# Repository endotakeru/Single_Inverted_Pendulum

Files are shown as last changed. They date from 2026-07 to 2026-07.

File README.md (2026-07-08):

# Single Inverted Pendulum — Simulation + Hardware Control

An educational control-systems project: a cart on a rail balances a rod with a
mass on the end (an inverted pendulum) using PD feedback. It spans the full
stack — a **Python simulation** to design and understand the controller, an
**Arduino controller** for the real hardware rig, the **CAD/3D-printed**
mechanical design, and the **KiCad schematic** for the electronics.

## What the system is

```
            o   <- end bob (mass m1)
            |
            |   <- rod (mass m2, length l), angle theta from vertical
         [ cart ]  <- slides on a rail
   =========================  <- rail
            |
        cart force / motion   --->
```

* **State vector (used throughout):** `X = [x, x_dot, theta, theta_dot]`
  * `x` cart position [m], `x_dot` cart velocity [m/s]
  * `theta` pendulum angle from vertical [rad] (0 = upright), `theta_dot` [rad/s]
* **The actuator moves the CART, not the pendulum.** The pendulum is never pushed
  directly — it only reacts to the cart sliding underneath it. Balancing means
  moving the cart so it stays under the falling pendulum.

## Project structure

```
Single_Inverted_Pendulum/
├── Python_Simulation/             # the Python simulation (design + study)
│   ├── main.py                    #   runs the whole simulation start to finish
│   ├── params.py                  #   constants, simulation settings, PD gains
│   ├── dynamics.py                #   nonlinear equations of motion (the plant)
│   ├── linear_model.py            #   linearised state-space A, B, C, D matrices + open-loop poles
│   ├── pd_controller.py           #   PD control law (angle loop + position loop)
│   ├── simulation.py              #   time-domain run with scipy solve_ivp
│   ├── plot_results.py            #   plots: position, angle, velocities, force
│   └── requirements.txt           #   pinned Python dependencies
├── Arduino_Control/
│   ├── arduino_IP/arduino_IP.ino  # main closed-loop PD controller for the physical rig
│   └── arduino_Calibration/       # staged bring-up sketches, run before arduino_IP.ino
│       ├── SensorCalibration/     #   zero the P3022 angle offset
│       ├── MotorTest/             #   verify stepper direction/speed/microstepping
│       ├── SensorReader/          #   raw sensor readout for debugging
│       └── FinalHardwareTest/     #   combined sensor + motor check before closing the loop
├── CAD/                           # Fusion 360 STEP files
│   ├── Assemblies/                #   Master_Assembly, Platform_Assembly, Extended_Rot_Sensor
│   ├── Custom/                    #   designed parts (platform, bearing slider, pendulum stick, spacers, ...)
│   └── Vendor/                    #   off-the-shelf parts (bearings, motor, shaft, T-slot rail, ...)
├── STL(3d_printing)/              # printable STLs for all custom/3D-printed parts
├── IP_Circuit_Schematics/         # KiCad project (Arduino + DRV8825 + P3022 wiring)
├── Dashboard_Simulation/
│   └── index.html                 # standalone browser version of the PD simulator
├── Single_IP_Project_Report.pdf   # full written project report
├── Hand_calculation.pdf           # hand-derived Lagrangian equations of motion
└── README.md                      # this file
```

---

## Part 1 — Python simulation (`Python_Simulation/`)

Design and study the controller in software first.

```bash
cd Python_Simulation
pip install -r requirements.txt
python main.py
```

Useful options:

```bash
python main.py                 # tuned balancing gains + plots (default)
python main.py --gains spec    # the spec gains (Kp_theta = 1) -> falls over & trips
python main.py --sweep         # sweep theta0 = -15..+15 deg; all angles overlaid (theta & x panels)
```

In the simulation the controller output is a **force** on the cart. Two PD loops
are **summed into one cart force**:

```
F = (Kp_theta*theta + Kd_theta*d theta/dt)   # angle loop (upright)
  + (Kp_x*x         + Kd_x*d x/dt)            # position loop (centre)
```

The default `params.py` gains (`Kp_theta = 1`) are intentionally too weak to
balance; `Params.balanced()` / `--gains preset` (`Kp_theta = 9.17`, `Kd_theta = 0.75`)
do balance. `linear_model.py` builds the linearised state-space matrices and
reports the open-loop poles (one at +7.19 rad/s — confirming the plant is
open-loop unstable). `Dashboard_Simulation/index.html` is the same simulator
in a browser — just open the file.

## Part 2 — Arduino controller (`Arduino_Control/`)

The closed-loop controller for the real rig lives in
`arduino_IP/arduino_IP.ino`.

- Board: **Arduino Uno R3** (powered over USB).
- Motor: **NEMA 17 stepper** driven by a **DRV8825 STEP/DIR driver** on a
  **separate 12–24 V supply**; the cart is moved by a GT2 belt/pulley.
- Sensor: **P3022** analog angle sensor read on **A0**.
- It reads the angle, runs a PD law, and converts the PD output into a stepper
  **direction + step frequency** (bigger error → step faster).

> **Important difference from the simulation:** the sim's actuator is a *force*;
> the stepper is a *velocity* command. So the simulation gains do **not** transfer
> directly — they are included in the sketch only as a reference. **Tune the
> hardware gains carefully**, starting small.

Before running `arduino_IP.ino`, bring the hardware up in stages using the
sketches in `arduino_Calibration/`:

1. **SensorCalibration** — zero the P3022 offset so upright reads 0°.
2. **MotorTest** — verify stepper direction/speed/microstepping, independent of the sensor.
3. **SensorReader** — raw sensor readout for debugging.
4. **FinalHardwareTest** — combined sensor + motor check before trusting the closed loop.

Open the sketch in the Arduino IDE, select *Arduino Uno*, and upload. Watch the
Serial Monitor at **115200 baud**.

## Part 3 — Mechanical design (`CAD/`, `STL(3d_printing)/`)

Designed in Fusion 360 as two STEP assemblies (`CAD/Assemblies/`), built from
custom parts (`CAD/Custom/`) and off-the-shelf vendor parts (`CAD/Vendor/`).
The cart rides a 0.540 m T-slot rail (usable half-travel ≈ 0.194–0.214 m)
driven by a belt/pulley; the pendulum pivots in a single vertical plane.
Printable STLs for every custom/3D-printed part (platform, bearing slider,
bearing housing, pendulum stick, T-slot holders, spacers, drill guides) are in
`STL(3d_printing)/`.

## Part 4 — Electronics (`IP_Circuit_Schematics/`)

KiCad project wiring the Arduino Uno R3, the DRV8825 driver, and the P3022
sensor, plus the RC noise filter on the sensor line and the smoothing
capacitor on the motor supply. **Before opening in KiCad, double check the
DRV8825 `RST`/`SLP` pins are tied to +5V, not GND** — they're active-low and
must be logic-high for the driver to run.

## Part 5 — Reports

- `Single_IP_Project_Report.pdf` — full write-up: modeling, control design,
  software/hardware implementation, results, and appendix.
- `Hand_calculation.pdf` — the hand-derived Lagrangian equations of motion.

---

## Notes / assumptions

* **Mass convention:** `m1` = end bob (point mass at the tip), `m2` = the rod —
  matches `B = l(m1 + m2/2)` and `C = l²(m1 + m2/3)`.
* **Default Arduino wiring** (unless changed): P3022 OUT→A0, STEP→D2, DIR→D3,
  ENABLE→D4, all grounds common, motor power from the external 12–24 V supply.
* **Controller naming:** the Python and Arduino control classes are named PD
  (`pd_controller.py`, `CartPolePD`) — there is no integral term in either
  implementation.

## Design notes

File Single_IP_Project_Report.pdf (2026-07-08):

# Cart-Pole Single Inverted Pendulum

Takeru Endo

June 2026

# 1 Introduction

## 1.1 Overview

Designed, simulated, and fabricated a nonlinear single inverted pendulum, derived the equations of motion, implemented real-time PD control with state estimation and sensor filtering, and integrated embedded hardware for closed-loop stabilization.

## 1.2 Final Demonstration

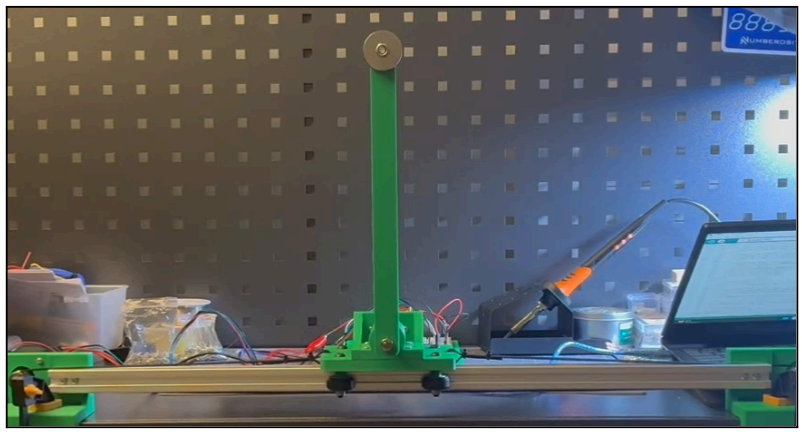
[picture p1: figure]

From the demo video:
https://drive.google.com/file/d/1Ql43lMNHcwXh4a7Qc4OHIrRiB7-3618u/view?usp=sharing
Settling Time | -Fully settles (within ±0.5°) in ≈ 0.7s - Cart re-centres within ±1 cm in ≈ 1.4s
Overshoot | -Pendulum swings through upright to the opposite side by ≈ 60–65% of θ₀. - Cart peak excursion ≈ 2.5cm to 4.7cm. - Stays inside the 21.4 cm rail half-travel. - Settles with little to no sustained oscillation.
Maximum Recoverable Angle | -7°~7°
Sampling Frequency | 200Hz

1

# 2 System Modeling

## 2.1 Summary

The cart-pole system was modeled as a nonlinear, coupled mechanical system using Lagrange’s method. The model includes the cart’s horizontal external force (Newtons) and the pendulum’s external rotational moment (Nm). Then, the equations were linearized using small angle assumptions along the upright equilibrium position of the pendulum, leading to the state-space model.

## 2.2 Lagrange’s Method

The following assumptions were made when deriving the equations of motion: the pendulum rod is rigid, the pendulum motion is confined to a single vertical plane, the cart motion is confined to a single horizontal axis, wheel slip is neglected, air resistance is negligible, gravitational acceleration is constant, and all frictional effects are neglected. To account for the distributed mass of the pendulum assembly, the combined center of mass of the end mass (m ) and pendulum rod ( ),
1 | m2
with its length defined as l, was determined rather than assuming a point mass at the pendulum tip. The pivot point of the pendulum on the cart (M) was defined as (x,0), where x represents the horizontal position of the cart. The location of the pendulum's center of mass was then determined.

Position of the pendulum’s centre of mass relative to the pivot (x, 0):

x

cm = x +

lsin(θ)(m1 +

m2

2

)
m1 + m2

y

cm =

lcos(θ)(m1 +

m2

2

)
m1 + m2

Total kinetic energy T (cart translation + pendulum translation and rotation about its own centre of mass):

T =

M
2

·(x')

2
+

m1
2

·(x'

2
+ 2l·cos(θ)·x'·θ' + l

2
·(θ')

2
)

+

m2
2

·((x')

2
+ l·cos(θ)·x'·θ' +

l

2
4

·(θ')

2
+

m2
24

·l

2
·(θ')

2
)

Potential energy V, taken at the pendulum’s centre of mass:

V = g·l·cos(θ)·(m1 +

m2
2

)

Lagrangian, and the Euler–Lagrange equations with respect to x and θ (F(t) and 0 are the corresponding generalized forces):

L = T − V | (1)

F(t) =

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
Carrying out the derivatives gives the nonlinear equations of motion, Equations (2) and (3):

F(t) = (M + m | (2)

1 + m2

)·x″ + l·(m1 +

m2
2

)·cos(θ)·θ″ − l·(m1 +

m2
2

)·sin(θ)·(θ′)²

0 = l·(m | (3)

1 +

m2
2

)·cos(θ)·x″ + l²·(m1 +

m2
3

)·θ″ − g·l·(m1 +

m2
2

)·sin(θ)

F(t) is the actuator force on the cart (Equation 2). The pendulum has no external moment applied to it directly, only the indirect coupling through x″ (Equation 3). Both feed the Python simulation (Section
4.1) and the linearised model below.

## 2.3 Linearization

About the upright equilibrium (θ = 0, θ′ = 0), apply the small-angle approximation (valid up to roughly 10-15°):

sin(θ) ≈ θ | cos(θ) ≈ 1 | θ·θ′ ≈ 0 | (θ′)² ≈ 0

Substituting into Equations (2)-(3) and solving for x″ and θ″ gives Equations (4)-(5):

x″ = ( | (4)

C
Δ

)·F(t) − (

B²g
Δ

)·θ

θ″ = − ( | (5)

B
Δ

)·F(t) + (

ABg
Δ

)·θ

with

A = M + m1 + m2

B = l·(m1 +

m2
2

) C = l²·(m1 +

m2
3

) Δ = A·C − B²

## 2.4 State-space Model

With X = [x, x′, θ, θ′]ᵀ and input u = F(t), Equations (4)-(5) assemble into the standard state-space form, Equation (6):

X′ = A | , | (6) mat

·X + Bmat

·u y = C
mat

·X + Dmat

·u

A

mat = [[0, 1, 0, 0], [0, 0, −

B²g
Δ

, 0], [0, 0, 0, 1], [0, 0,

ABg
Δ

, 0]]

Bmat = [0,

C
Δ

, 0, −

B
Δ

]ᵀ

C

mat = [[1, 0, 0, 0], [0, 0, 1, 0]] Dmat = 0

y = [x, θ]ᵀ is what the controller actually has: x dead-reckoned from the stepper step count, and θ from the P3022 sensor; neither velocity is measured directly. Numerically (Table 4, Section 8), the open-loop poles are {0, 0, +7.19, −7.19} rad/s which were calculated by deriving the eigenvalues of A through linear_model.py (section 4.1). The right-half-plane pole means the plant is unstable mat

without the PD controller of Section 3.

3

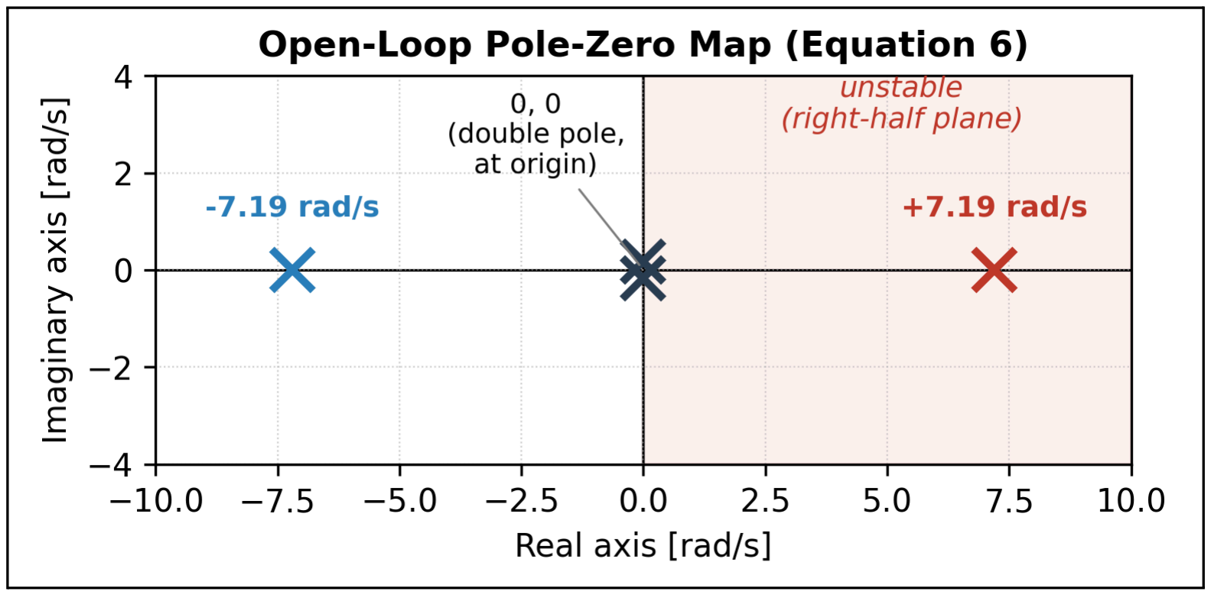
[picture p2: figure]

Figure 1: Open-loop pole-zero map

4

# 3 Control System Design

## 3.1 Overview

Two PD loops run on a single actuator command where in both simulation and real hardware, its output is force (Newtons). However, in hardware, the value is then translated to velocity through integration of acceleration (F = ma) and step value at 200 Hz. The angle is sensed using a P3022 rotary sensor. It is then driven by the PD controller to bring θ to the upright position at 0°. This action is prioritized over position centering. As for position, it is dead-reckoned from the stepper step count and the position PD gently pulls x towards the center point 0 so the cart stays centred on the rail. The inclusion of a second PD controller for position was necessary due to the limiting usable cart travel length.

## 3.2 Closed-Loop Architecture

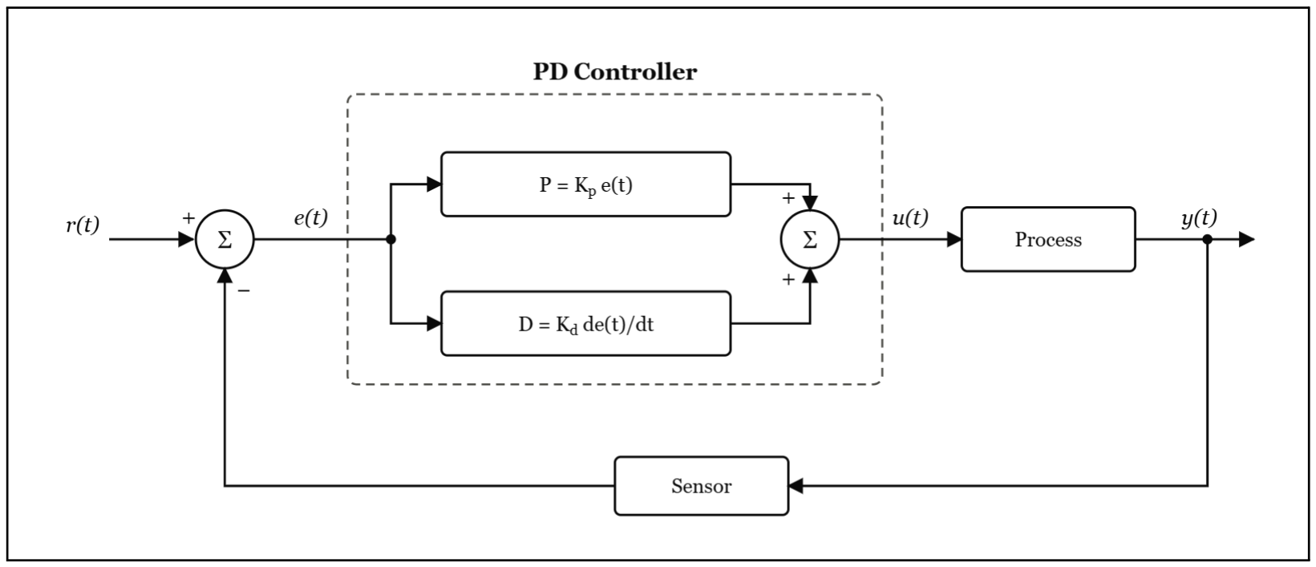
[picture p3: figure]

Figure 2: Block Diagram of Closed-Loop Feedback System with PD Control

## 3.3 PD Control Law

u(t) = (K | (7)
p_θ

e(t) + Kd_θ

de(t)
dt

) + (K
p_x

e(t) + Kd_x

de(t)
dt

)

## 3.4 Gain Tuning Methodology

Treating the pendulum angle dynamic as a damped second-order system, and choosing a target natural frequency ω and damping ratio ζ, the linearised θ″ equation (Section 2.3) gives the gains directly,
n
Equations (8)-(11):
K | (8)

p_θ = A·g + (

Δ
B

)·ωn

²

K | (9)

d_θ = 2ζ·(

Δ
B

)·ωn

K | (10)

p_x = (5–20%)·K
p_θ

5

K | (11)

d_x = 2ζ·√(K
p_x

·M
total

)

The position loop is kept much weaker than the angle loop so re-centring the cart never competes with staying upright (Section 3.1). These estimates were refined in simulation by sweeping initial θ =
−15°…+15° (Section 4.1), giving the preset gains K | = 9.17, | = 0.75, | = 1, | = 1.5. The
p_θ

Kd_θ

K
p_x

Kd_x

hardware was then re-tuned from small values, since the simulation actuator is a force and the stepper is a velocity command (Section 4.2).

The derivative term in both loops is also low-pass filtered (pd_controller.py, arduino_IP.ino) so sensor noise is not amplified by differentiation. The filter's time constant τd sets its cutoff frequency, Equation (12):

f | | | | (12)

τd_cutoff = 1 / (2π·τd)

With τd = 0.02 s, f | ≈ 8 Hz, comfortably above the pendulum’s own ≈1.1 Hz dynamics (the
τd_cutoff
±7.19 rad/s eigenvalues of Section 2.4) so the filter adds little phase lag to the signal the derivative term needs to track, while still smoothing sample-to-sample ADC noise well below the 200 Hz control rate.

6

# 4 Software Implementation

## 4.1 Simulation - Python

The Python simulation (Python_Simulation/) implements the nonlinear plant (Equations 2-3) and the PD controller (Equation 7), so the control law could be designed and checked in software before it went on the physical rig.

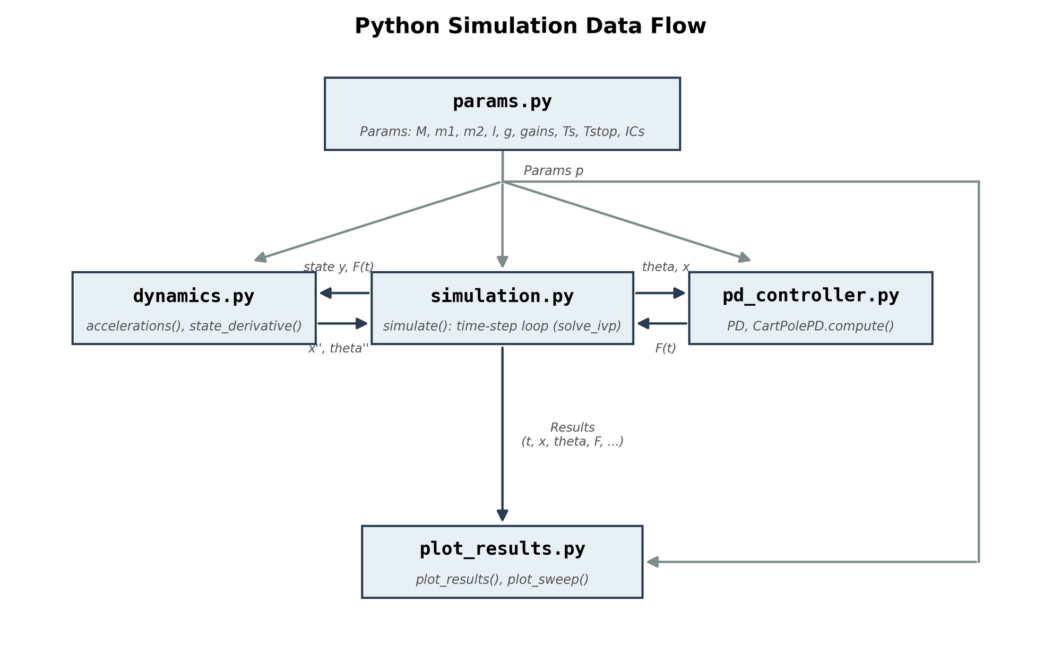
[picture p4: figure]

Figure 3: Simulation data flow between params.py, dynamics.py, pd_controller.py, simulation.py, and plot_results.py

dynamics.py solves the 2×2 mass matrix for x″ and θ″ at every step (np.linalg.solve), and simulation.py integrates the result with SciPy’s solve_ivp (“RK45”) at Ts = 5 ms, the same rate used on the hardware. linear_model.py builds the state-space matrices of Equation (6) and computes the open-loop poles as the eigenvalues of A (open_loop_poles()), where main.py prints these at mat

start-up to confirm the instability before any control is applied. The CartPolePD class (pd_controller.py) sums two PD loops, angle and position, into one cart force, saturated at ±60 N with a filtered derivative and conditional anti-windup. Only kp and kd are tuned for either loop (Section 3.4), so the law actually exercised in this report is the PD law of Equation (1), not a tuned PD. main.py runs a single balance (python main.py) or a full angle sweep (python main.py --sweep, Figure 9, Section 6.1). --gains preset uses the tuned gains of Section 3.4, and --gains spec uses the intentionally weak defaults that fall over, to show why tuning mattered.

## 4.2 Embedded Controller - ARDUINO

The embedded controller (Arduino_Control/arduino_IP/arduino_IP.ino) runs the same PD law on the physical rig at a fixed 200 Hz, matching the simulation’s step time (Ts).

7

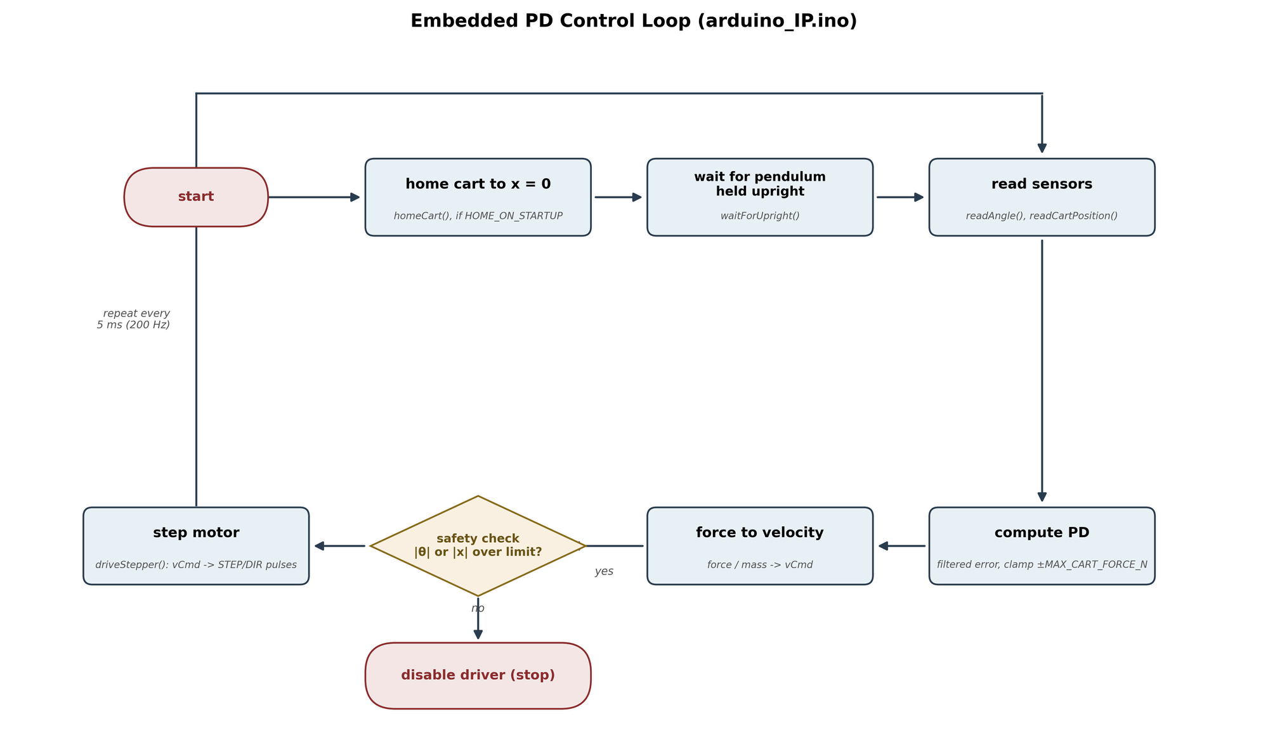
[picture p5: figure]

Figure 4: Flowchart of embedded control loop

Each tick it reads the P3022 sensor (readAngle(), 6× oversampled) and the dead-reckoned cart position (readCartPosition()), then computes a filtered derivative error using the derivative cutoff frequency (Equation 12) for both loops (computePD()) and sums them into a force command clamped to ±MAX_CART_FORCE_N. Due to the fact that the stepper is a velocity command, not a force, that force is integrated (force/mass) into a commanded velocity vCmd and converted to STEP/DIR pulses (driveStepper()). This is the one place the simulation and the hardware genuinely differ. A safety check (safetyCheck()) disables the driver if |θ| or |x| exceed their limits. At start-up the sketch can crash-home the cart to x = 0 (HOME_ON_STARTUP) and waits for the pendulum to be held upright
before arming the loop (waitForUpright()). The hardware gains (K | = 11.0, | = 1.7, | = 2.0,
p_θ

Kd_θ

K
p_x
K = 1.2) were re-tuned on the bench from small values, using the simulation’s preset gains only as a
d_x
reference (Section 3.4).

8

# 5 Hardware Implementation

## 5.1 Mechanical Design

The rig was designed in Fusion 360 as two STEP assemblies (CAD/Assemblies/, custom parts in CAD/Custom/, vendor parts in CAD/Vendor/), shown in Figure 5. The cart rides a 0.540 m T-slot rail (usable half-travel ≈ 0.194-0.214 m) driven by a GT2 belt/pulley, while the pendulum pivots in a single vertical plane.

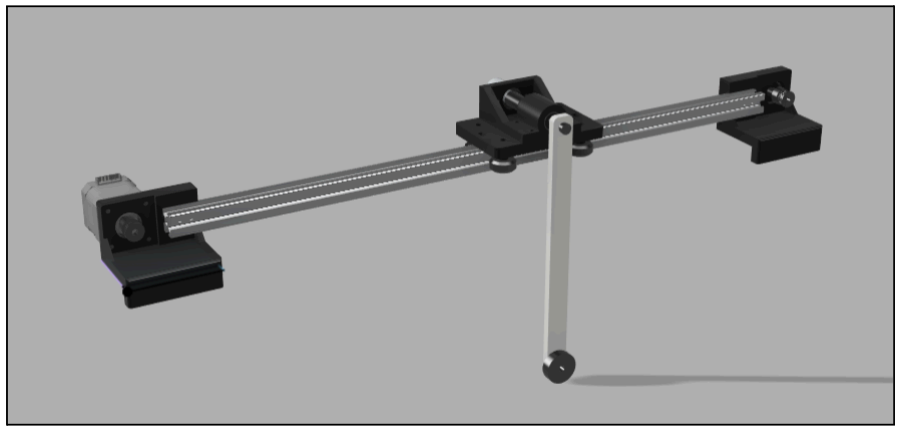
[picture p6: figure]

Figure 5: Fusion 360 master-assembly render

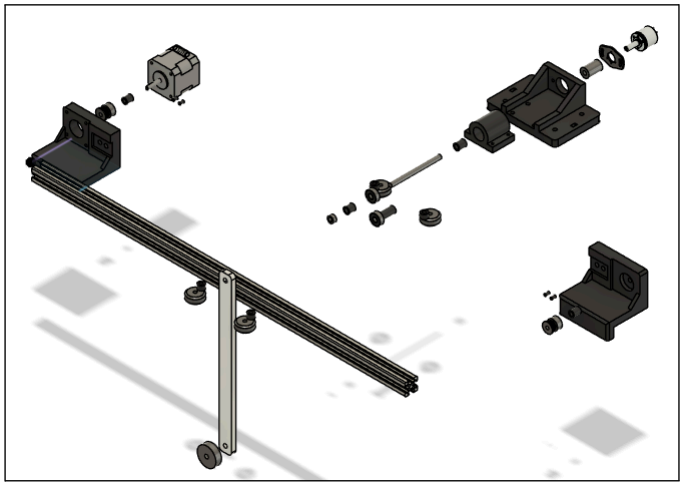
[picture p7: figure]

Figure 6: Exploded-view of master assembly

Custom parts (platform, bearing slider/housing, pendulum stick, T-slot holders, spacers, drill guides) were 3D-printed in PLA. Bearings, shaft, motor, and fasteners are off the shelf. Printed drill guides (STL(3d_printing)/Drill_Guide/) kept hole placement repeatable. Full BOM in Table 1.

9

Component | Spec / Notes | Qty | Source
Arduino Uno R3 Kit (includes: capacitors, resistors, 26-28 AWG jumper wires, breadboard) | ATmega328P, USB-powered logic, Prototype wiring, Noise filtering | 1 set | Amazon
DRV8825 stepper driver | STEP/DIR driver | 1 | Amazon
NEMA 17 stepper motor | 1.8°/step (200 steps/rev), 4-wire bipolar | 1 | Amazon
P3022 rotary angle sensor | 12-bit (read 10-bit on Arduino A0) | 1 | Amazon
12–24 V DC power supply | Motor power only | 1 | Amazon
GT2 belt + 20T pulley | 2 mm pitch, 0.040 m circumference | 1 set | Amazon
Aluminium T-slot rail | 0.540 m linear axis | 1 | Amazon
606-2RS bearings | Pendulum pivot bearings | 2 | Amazon
V-slot 625ZZ bearings | Cart roller bearings | 4 | Amazon
D-shaft + shaft coupler + collar | Pendulum pivot | 1 set | Amazon
Pendulum rod + end mass | m2 = rod (l = 0.250 m), m1 = end bob | 1 | Printed
3D-printed PLA parts | Platform, slider, housings, holders, spacers, drill guides | set | Printed
M3 / M5 / M6 fasteners + spacers | Assembly hardware | as needed | Amazon / Printed
22 AWG copper stranded wire | Motor power transmission wires | 1 set | Amazon

Table 1: Bill of materials

## 5.2 Electronics

Wiring is captured in a KiCad project (IP_Circuit_Schematics/): Arduino Uno R3, DRV8825 driver, P3022 sensor, 220 ohm resistor & 10µF capacitor for P3022 output noise filtering, and a 100 µF smoothing capacitor across the driver’s motor-supply input as shown in Figure 7 below.

10

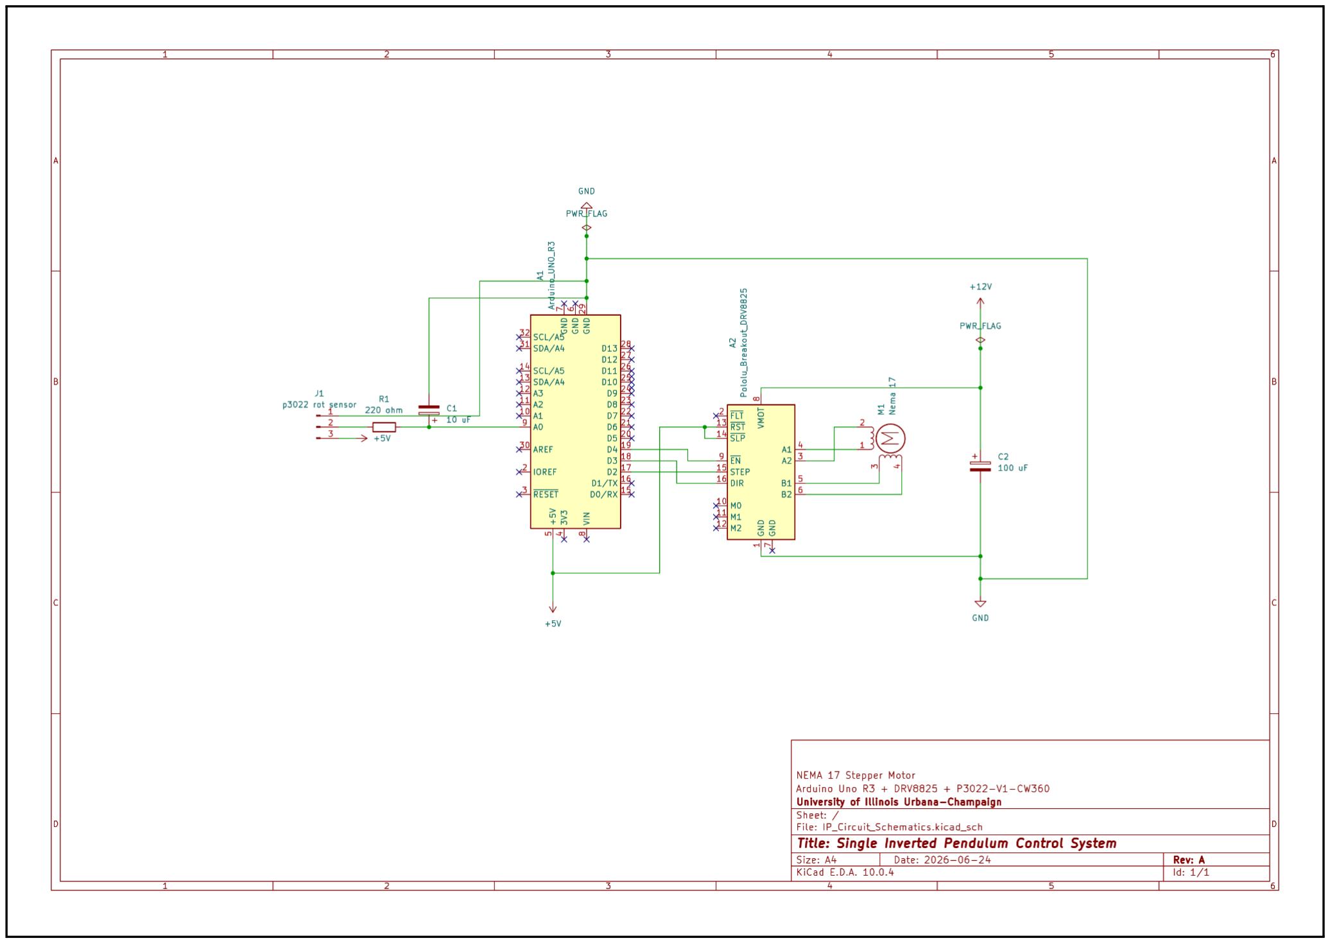
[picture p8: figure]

Figure 7: KiCad circuit schematic

The 10 µF capacitor was selected because it was the smallest capacitance available in my inventory. A 220 Ω resistor was then chosen to pair with the capacitor by applying the Nyquist sampling criterion and the RC cutoff frequency equation. Equations (13)-(14) as shown below.

f | (13) Nyquist =

f
sampling
2 =

200Hz
2 | = 100Hz
f | (14)

RC_cutoff =

1
2π·R·C = 72. 3Hz

A 100 µF smoothing capacitor was placed across the DRV8825 motor-supply input following the manufacturer's recommendation to provide bulk energy storage, reduce supply voltage fluctuations, and protect the driver from inductive voltage spikes generated during stepper motor operation

Signal | Arduino / Driver Pin | Notes
P3022 OUT | A0 | angle = SENSOR_SIGN × (raw − ANGLE_OFFSET_COUNTS) × (360/1024)
P3022 VCC / GND | 5 V / GND | shared ground with driver and motor supply
DRV8825 STEP | D2 | one microstep per pulse
DRV8825 DIR | D3 | sets direction
DRV8825 EN | D4 (active-low) | disabled on a safety trip

11

Motor power | separate 12–24 V DC | never from the Arduino 5 V rail

Table 2: Pin connections between the P3022 sensor, the DRV8825 driver, and the Arduino Uno

The Arduino runs on USB 5 V logic only while the NEMA 17 draws from a separate 12-24 V supply through the driver. With 200 full steps/rev and the 0.040 m pulley, METERS_PER_STEP = 0.040/(200 × microsteps). The NEMA 17’s two coil pairs (found by continuity check) go to the driver’s A+/A− and B+/B− terminals.

## 5.3 Hardware Validation Protocols

The hardware was brought up in stages, each verified before it was trusted inside the closed loop, shown in Figure 8.

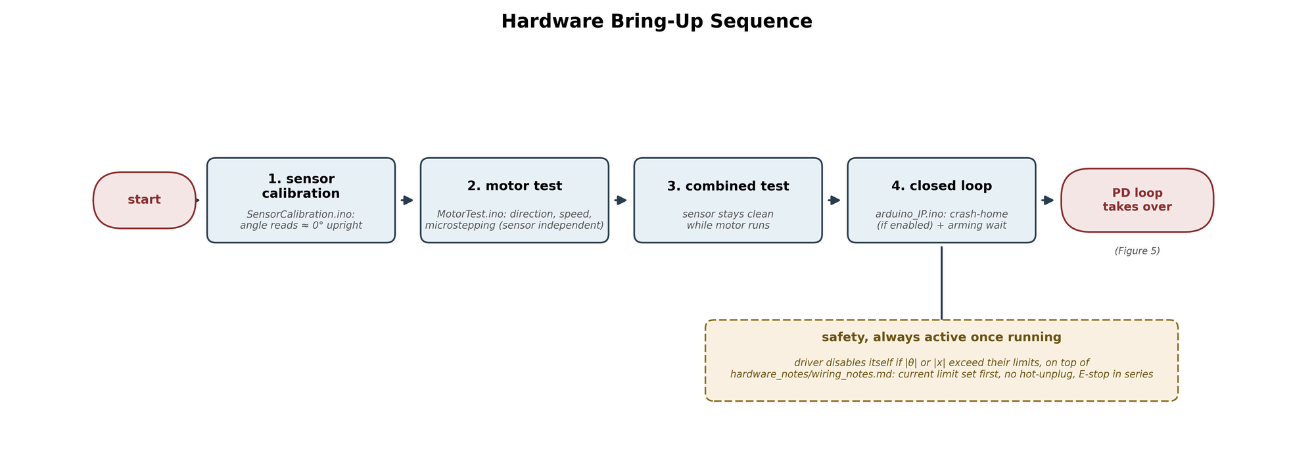
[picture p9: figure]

Figure 8: Flowchart of hardware bring-up sequence

Sensor calibration confirms the angle reads ≈ 0° upright and motor testing confirms direction, speed, and microstepping independent of the sensor. The reason is because a combined test checks if the sensor stays clean while the motor runs. Only then is the full arduino_IP.ino sketch run as a closed loop, with crash-homing (if enabled) and an arming wait before the PD loop takes over. The driver disables itself if |θ| or |x| exceed their limits: set the driver current limit first, never hot-unplug the motor, and add a physical E-stop in series with the motor supply.

12

# 6 Results

## 6.1 Simulation Environment

With the preset PD gains (K | = 9.17, | = 0.75, | = 1, | = 1.5), every starting angle from
p_θ

Kd_θ

K
p_x

Kd_x

−15° to +15° recovers to upright with no rail contact, and re-centres within roughly 3-4 s (Table 3, Figure 9). The opposite-side overshoot is 60-65% of θ₀, and the cart excursion stays well inside the ±21.4 cm rail half-travel.

θ₀ (deg) | Peak |θ| (deg) | Opposite-side overshoot (deg) | Peak |x| (cm) | Result
±15 | 15.00 | 10.0 | 16.0 | Upright
±10 | 10.00 | 6.5 | 10.4 | Upright
±5 | 5.00 | 3.2 | 5.1 | Upright
0 | 0.00 | 0.0 | 0.0 | Upright

Table 3: Simulated peak angle, overshoot, and cart excursion vs. starting angle (preset PD gains)

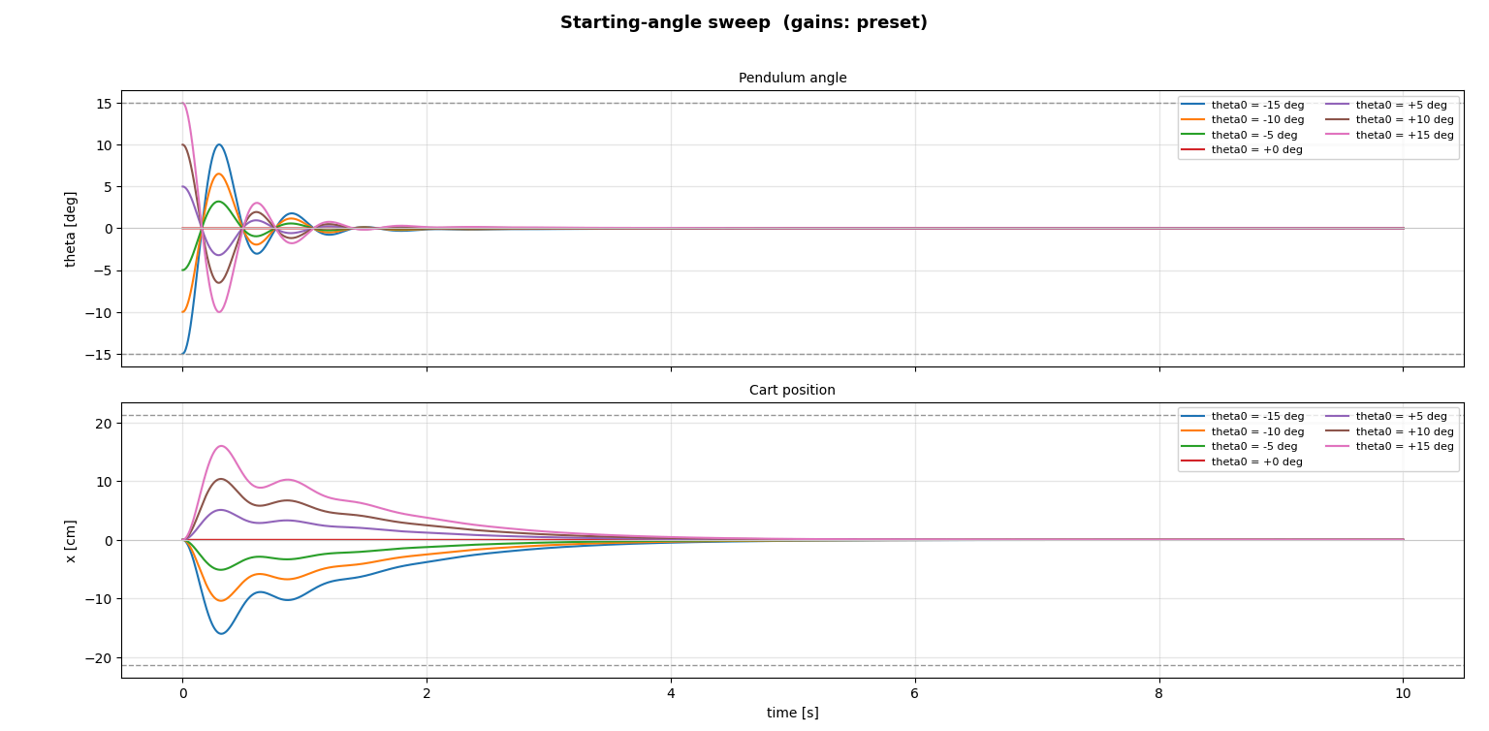
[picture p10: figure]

Figure 9: Simulated pendulum angle (top) and cart position (bottom) vs. time for θ₀ = −15°…+15° (preset PD

gains, python main.py --sweep)

## 6.2 Hardware System

As already reported in Section 1.2, the hardware settles to within ±0.5° in ≈0.7 s and re-centres to within ±1 cm in ≈1.4 s, with overshoot and cart excursion in the same range as simulation (60-65% of θ₀, 2.5-4.7 cm). The demonstrated recoverable range (±7°) is narrower than simulation’s (±15°), most likely from the 10-bit ADC resolution, the discretised velocity-command stepper versus the simulation’s continuous force, and unmodeled belt/bearing friction. Cart force stayed within ±60 N throughout.

13

## 6.3 Mechanical Challenges

Most of the mechanical difficulty was in alignment and repeatability, not the parts themselves (Figure 10). Printed drill guides (STL(3d_printing)/Drill_Guide/) kept rail and platform hole placement accurate enough for the cart to roll freely, and several print iterations were needed to get PLA part tolerances around the bearings and D-shaft right without forcing. Moreover, because the cart position is dead-reckoned from the step count, any belt slack or missed step corrupts the position estimate directly, so belt/pulley fit mattered as much as gain tuning. Finally, the crash-homing routine exists to re-establish a known x = 0 at start-up rather than assume it.

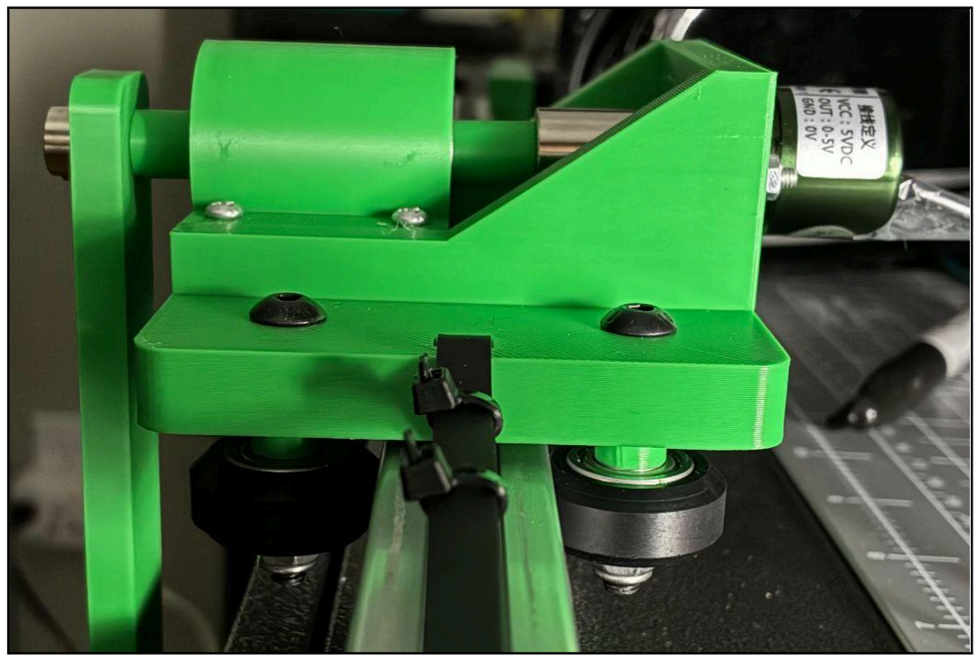
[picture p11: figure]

Cart bearings and T-slot fit

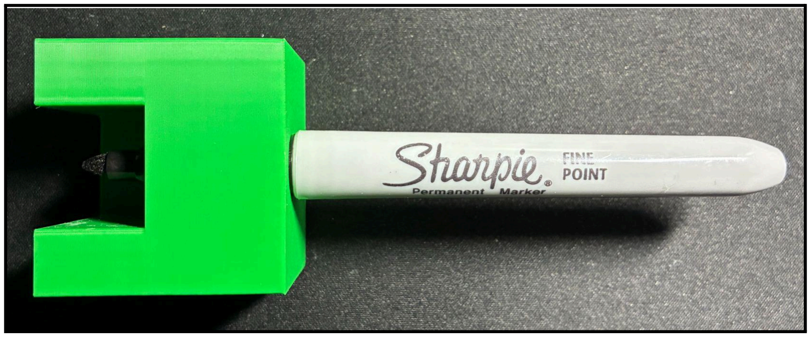
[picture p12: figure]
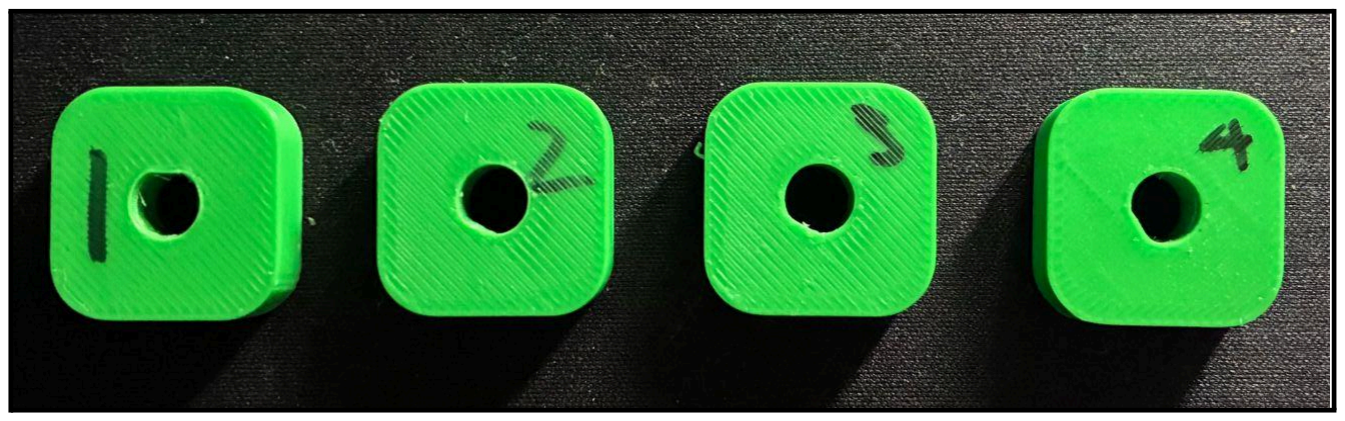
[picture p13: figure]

Pendulum stick D-shaft hole | Drill guide
(Tight Fit [Left] -> Loose Fit [Right]) | (Helps draw precise drilling point)

Figure 10: A mechanical fit/alignment issue encountered during assembly.

14

# 7 Conclusion and Future Work

## 7.1 Lessons Learned

The biggest lesson was control system design: stabilising an open-loop-unstable plant (a pole at +7.19 rad/s), estimating PD gains from a damped second-order heuristic model instead of pure trial and error, and balancing two competing objectives, upright angle and a centred cart, through one actuator command. Deriving the nonlinear equations of motion with Lagrange’s method and building the A/B/C/Δ model let stability be checked directly from eigenvalues rather than by trial and error on hardware. On the embedded and mechanical side, writing a fixed-rate (Ts = 5 ms) real-time loop in C++/Arduino, and designing a belt-driven cart on a T-slot rail with 3D-printed parts, both required planning for travel limits and manufacturability up front (Section 6.3). None of it worked until the staged bring-up of Section 5.3, calibration, then motor test, then a combined test, and only then the closed loop, was in place.

## 7.2 Future Improvements

Control theory: replace the hand-tuned PD law with LQR on the state-space model of Section 2.4, and add a better filtering system like Kalman filter to estimate velocity instead of differentiating noisy measurements.
Hardware: read the P3022 digitally for its full 12-bit resolution, add a real cart-position encoder or limit switches instead of dead-reckoning, improve on noise filtering measurements by utilizing a ceramic capacitor with lower capacitance, and implement a larger gear ratio for faster response and larger recoverable angle.

15

# 8 Appendix

Detailed parameters, derived constants, and analysis, matching the current Python_Simulation/params.py and Arduino_Control/arduino_IP/arduino_IP.ino. Table 3 lists the physical parameters used throughout this report.

Physical parameters

Symbol | Meaning | Value
M | Cart mass | 0.220 kg
m1 | End bob (point mass at rod tip) | 0.042 kg
m2 | Pendulum rod mass | 0.018 kg
l | Rod length | 0.250 m
g | Gravity | 9.81 m/s²
Rail length / cart length | Usable half-travel = (0.540 − 0.112)/2 | 0.540 m / 0.112 m → 0.214 m

Table 4: Physical parameters of the cart-pendulum system

Derived constants and stability: evaluating A, B, C, and Δ from Section 2.3 with the physical parameters of Table 4 gives

A = M + m1 + m2 = 0. 280 kg

B = l·(m1 +

m2
2

) = 0. 250·(0. 042 + 0. 009) = 0. 01275

C = l²·(m1 +

m2
3

) = 0. 0625·(0. 042 + 0. 006) = 0. 00300

Δ = A·C − B² = 0. 00084 − 0. 0001626 = 0. 000677

so the open-loop (plant) poles are {0, 0, +7.19, −7.19} rad/s. The single right-half-plane pole confirms the plant is unstable, and the minimum K needed just to balance is A·g = 0.280 × 9.81 = 2.75 N/rad.
p_θ
Numeric state-space matrices: substituting the same constants into Equation (6) gives

A

mat = [[0, 1, 0, 0], [0, 0, − 0. 240, 0], [0, 0, 0, 1], [0, 0, 51. 66, 0]]

(row 2 =−

B²g
2

, row 4 =

ABg
Δ

)

Bmat = [0, 4. 430, 0, − 18. 83]ᵀ (= [0, C/Δ, 0, − B/Δ]ᵀ)

C

mat = [[1, 0, 0, 0], [0, 0, 1, 0]] Dmat = 0

Controller gains: Table 5 compares the simulation preset gains against the gains currently in arduino_IP.ino.

16

Gain | Simulation (preset) | Hardware (arduino_IP.ino)
K p_θ | 9.17 11.0
Kd_θ | 0.75 1.7
K / Kd_x p_x | 1 / 1.5 | 2.0 / 1.2
Derivative filter τd | 0.02 s | 0.02 s
Actuator limit | ±60 N (force) | ±60 N (force) → step interval 500–6100 µs

Table 5: Controller gains, simulation preset vs. hardware

Hardware constants: the following geometric and safety constants are taken directly from arduino_IP.ino as currently checked in:

METERS_PER_STEP = 0. 040 / (200 × 1) = 2. 0×10⁻⁴ m/step

(0.20 mm/step, full-step; MICROSTEPS = 1 in the current sketch) control rate = 5 ms = 200 Hz ADC scale = 360 / 1024 = 0. 3516 deg/count (10 bit) safety trips = |θ| > 90° (7 sample debounce) or |x| > 0. 22 m

Note that these safety-trip and step-geometry constants reflect arduino_IP.ino as currently checked in. Earlier design notes used a tighter |θ| > 15° / |x| > 0.194 m trip and a 16× microstep setting.

17

# 9 Project Repository

- GitHub repository: github.com/endotakeru/Single_Inverted_Pendulum/tree/main
- CAD files: /CAD (STEP assemblies in Assemblies/, custom parts in Custom/, vendor parts in Vendor/) and /STL(3d_printing) (printable parts, including Drill_Guide/).
- Hand calculations:
drive.google.com/file/d/140igMz2Y46unPIWgm3RWE6VgtJxZAJj0/view?usp=sharing
- Schematics: /IP_Circuit_Schematics (IP_Circuit_Schematics.kicad_sch).
- Simulation code: /Python_Simulation (main.py, dynamics.py, linear_model.py, pd_controller.py, simulation.py, plot_results.py, params.py).
- Embedded code: /Arduino_Control/arduino_IP/arduino_IP.ino, plus any calibration or motor-test sketches used during bring-up (Section 5.3).
- BOM: Table 1 (Section 5.1).
- Interactive demo: /Dashboard_Simulation/index.html, a browser version of the simulator.

18

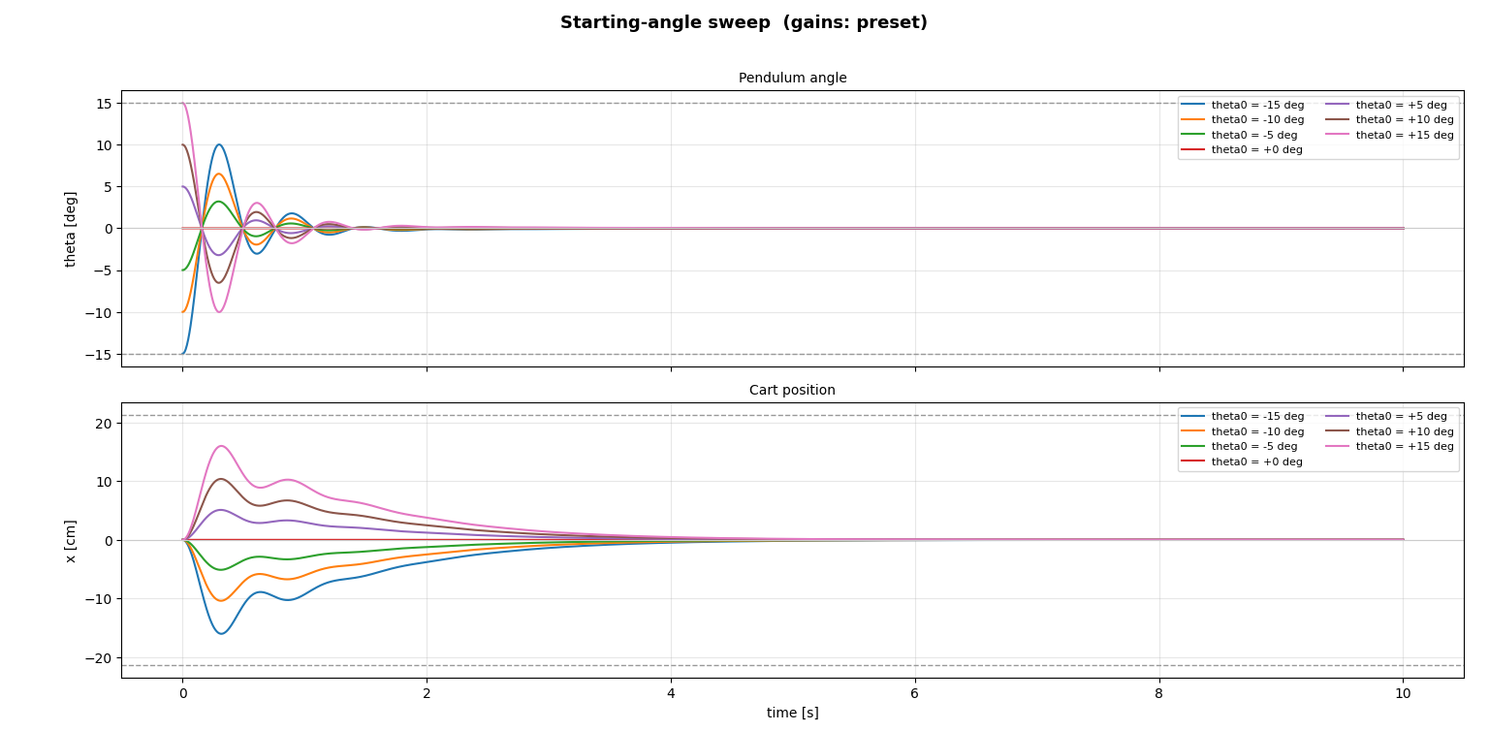
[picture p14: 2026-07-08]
simulated_gains.png

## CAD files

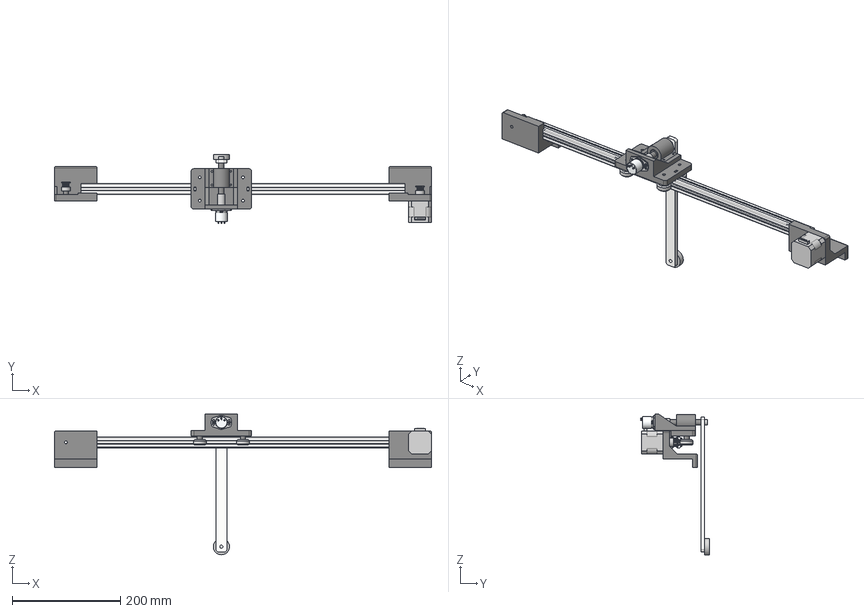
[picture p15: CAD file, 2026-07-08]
CAD/Assemblies/Master_Assembly.step
697.9 x 127.4 x 260.1 mm
NEMA 17 Motor
GT2 Pulley Gear meta-matic-generator 1.0 -72ebf523141e x 2
Tslot_Aluminium_Profile
Tslot_Holder1
Tslot_Holder2
M5_Spacer_11.5mm
M5_Spacer_7mm x 4
Platform
vslot tekerlek x 4
Shaft_Coupler
Hall Potentiometer PANDAUTO P3022-V1-CW360
D_Shaft
M6_Spacer_11.81mm
Shaft_Collar
Pendulum_Stick
606_2RS x 2
M6_Spacer_10.19mm
M6_Spacer_23mm
606-2RS Housing
M5_Spacer_10mm
M3_Thin_Spacer x 4
Pendulum_Weight

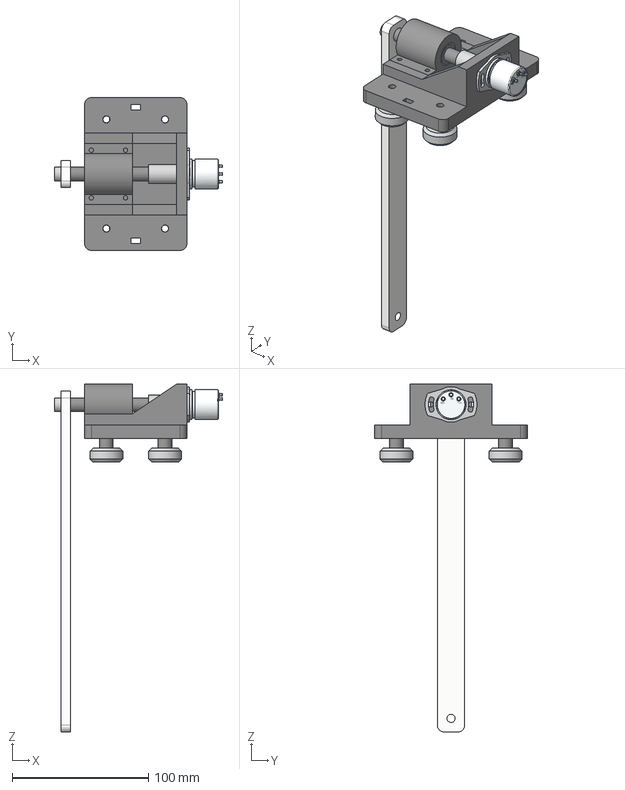
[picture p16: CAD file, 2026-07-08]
CAD/Assemblies/Platform_Assembly.step
123.4 x 112.0 x 255.2 mm
M5_Spacer_7mm x 4
Platform
vslot tekerlek x 4
Shaft_Coupler
Hall Potentiometer PANDAUTO P3022-V1-CW360
D_Shaft
M6_Spacer_11.81mm
Shaft_Collar
Pendulum_Stick
606_2RS x 2
M6_Spacer_10.19mm
M6_Spacer_23mm
606-2RS Housing

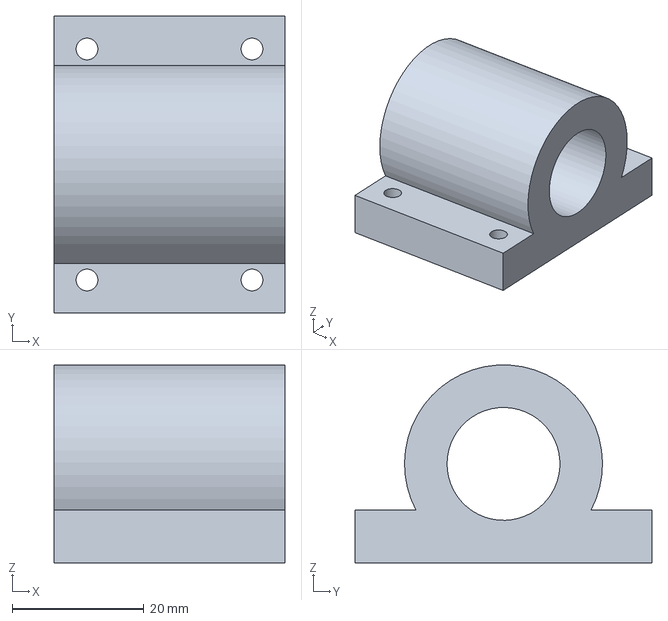
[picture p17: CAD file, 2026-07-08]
CAD/Custom/606-2RS Housing.step
35.0 x 45.0 x 30.0 mm

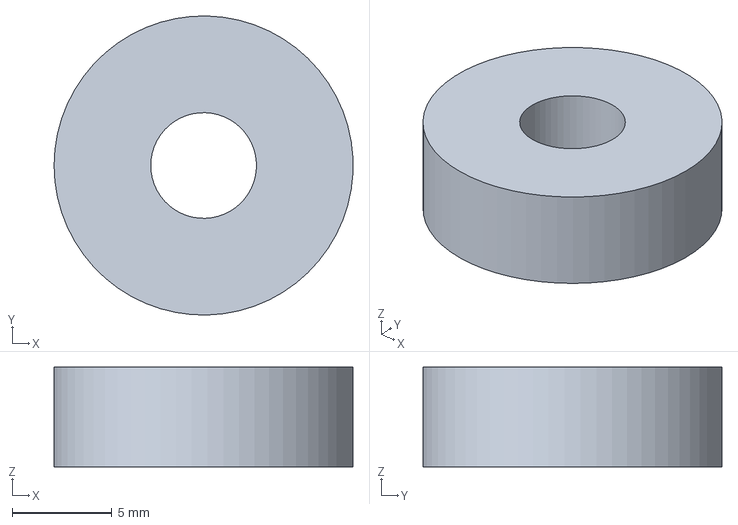
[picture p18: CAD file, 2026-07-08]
CAD/Custom/Spacers/M5_Thick_Spacer.step
15.0 x 15.0 x 5.00 mm

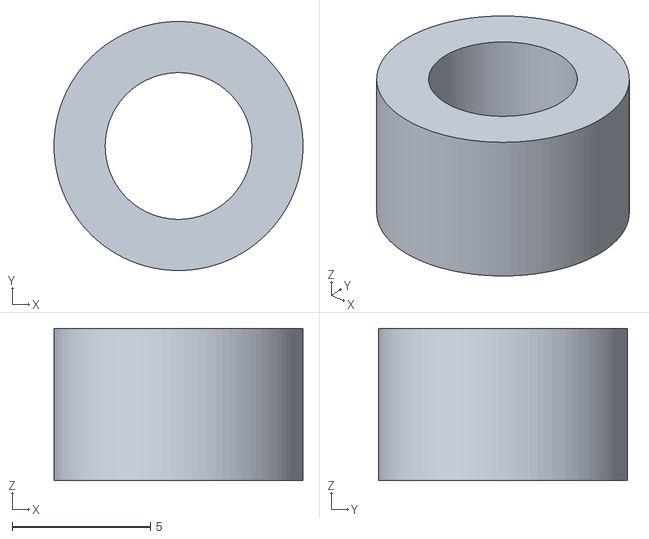
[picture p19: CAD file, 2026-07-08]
STL(3d_printing)/M5_Spacer_5.5mm(IdlerGearSpacer).stl
9.00 x 9.00 x 5.50

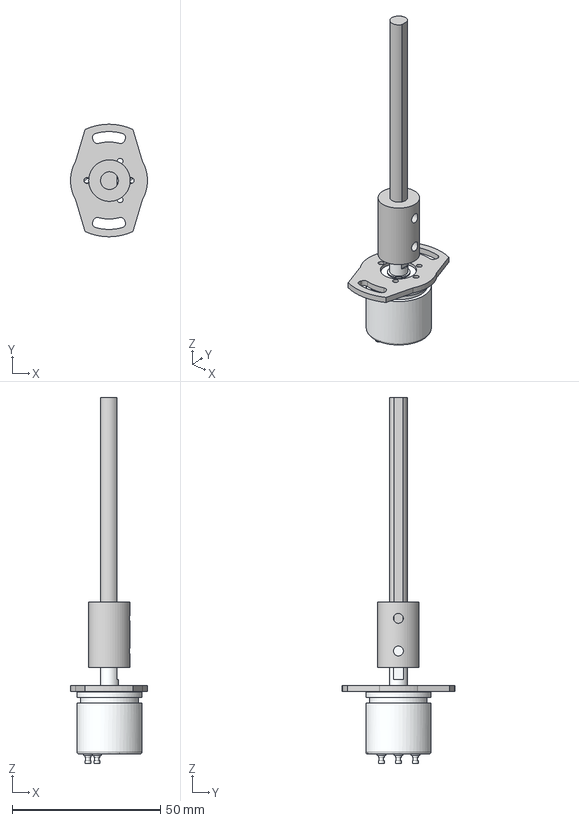
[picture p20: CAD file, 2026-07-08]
CAD/Assemblies/Extended_Rot_Sensor.step
26.0 x 38.0 x 123.4 mm
Shaft_Coupler
Hall Potentiometer PANDAUTO P3022-V1-CW360
D_Shaft

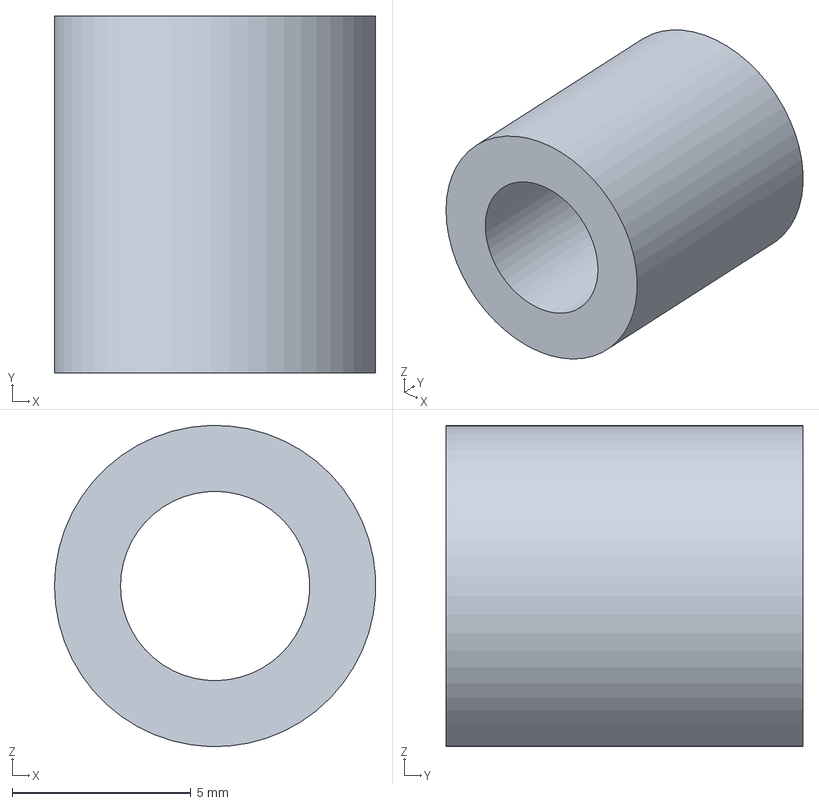
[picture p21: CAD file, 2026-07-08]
CAD/Custom/Spacers/M5_Spacer_10mm.step
8.99 x 10.0 x 9.00 mm

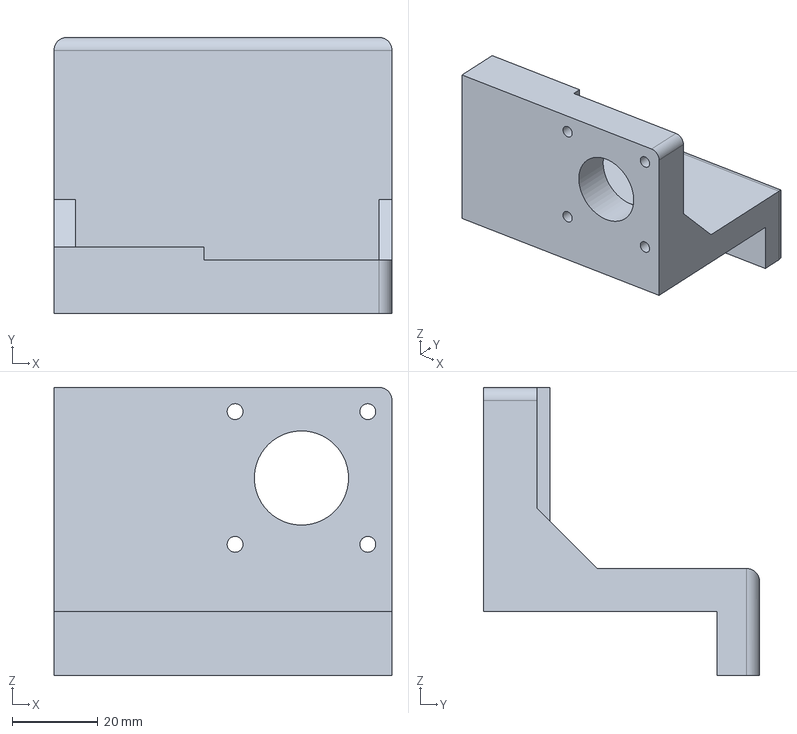
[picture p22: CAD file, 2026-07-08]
CAD/Custom/Tslot_Holder1.step
78.9 x 64.5 x 67.3 mm

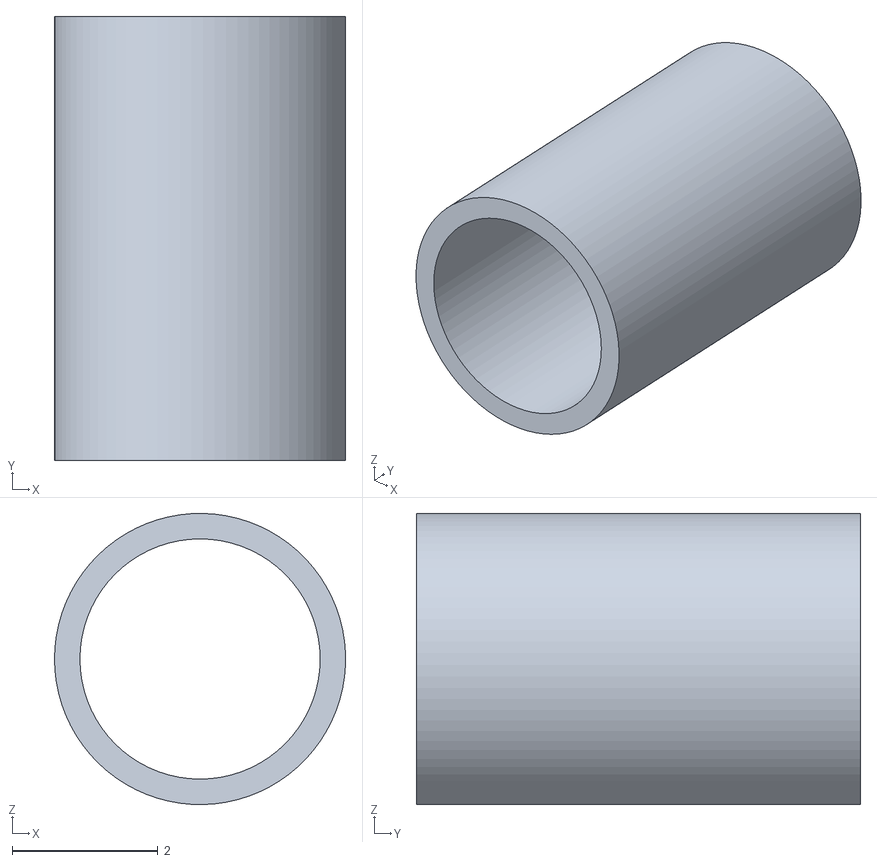
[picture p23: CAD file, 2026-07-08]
STL(3d_printing)/M3_Thin_Spacer4.stl
4.00 x 6.10 x 4.00

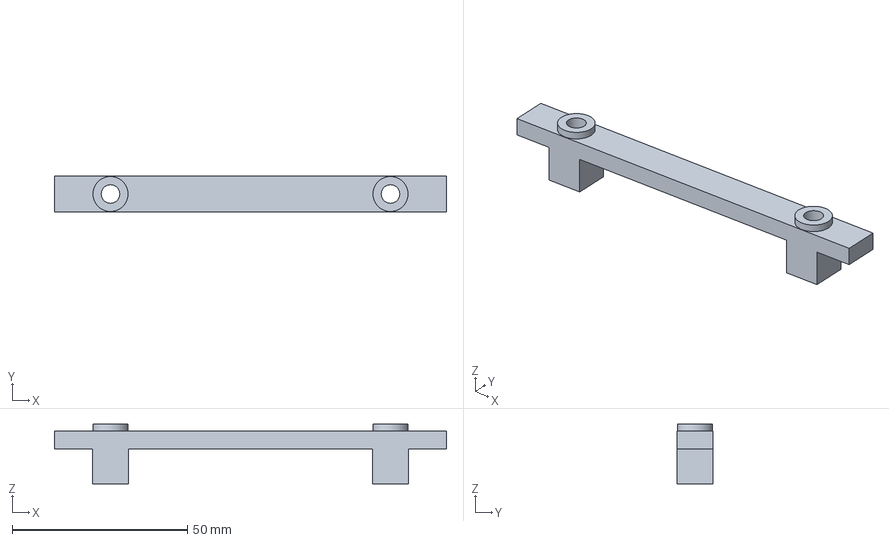
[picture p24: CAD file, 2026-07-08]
CAD/Custom/Bearing _Slider.step
112.0 x 10.3 x 17.0 mm

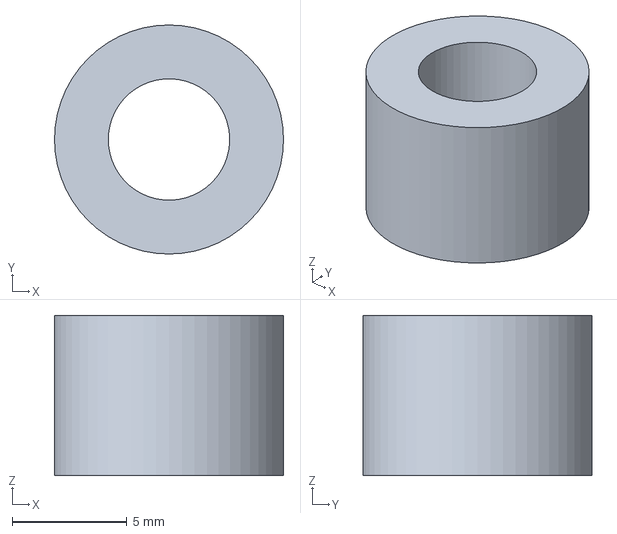
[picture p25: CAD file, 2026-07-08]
CAD/Custom/Spacers/M5_Spacer_7mm.step
10.0 x 10.0 x 7.00 mm

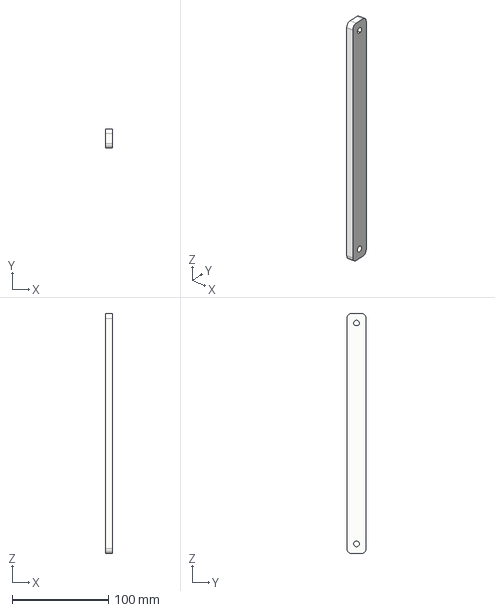
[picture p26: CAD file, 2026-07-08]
CAD/Custom/Pendulum_Stick.step
7.00 x 20.0 x 250.0 mm

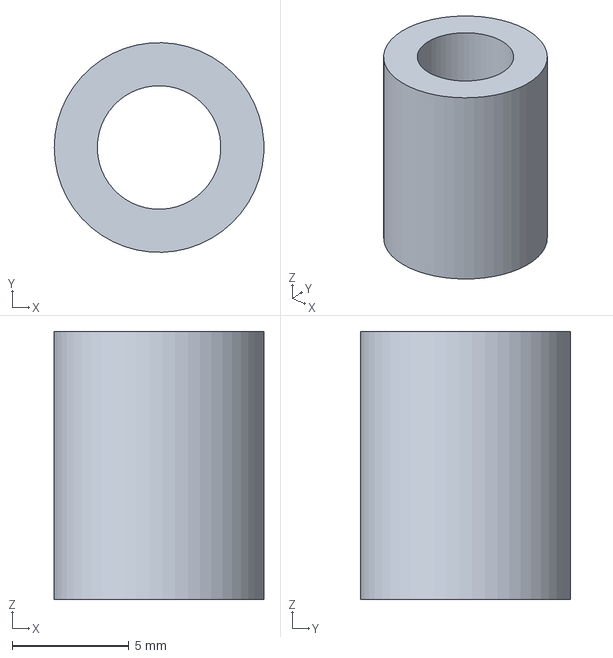
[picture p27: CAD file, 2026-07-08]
CAD/Custom/Spacers/M5_Spacer_11.5mm.step
8.99 x 9.00 x 11.5 mm

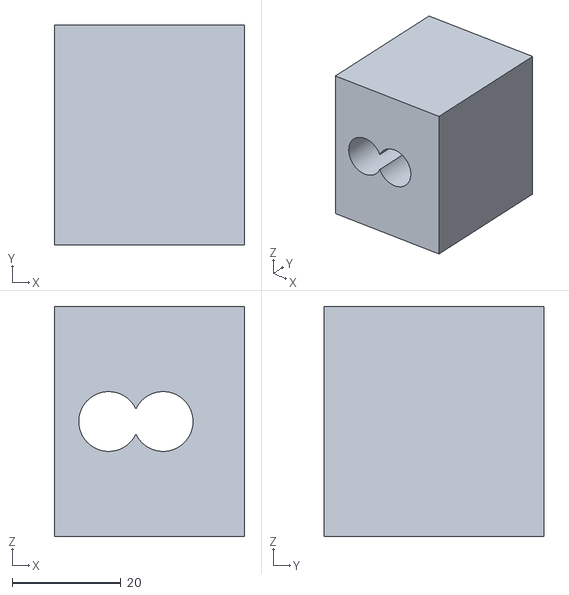
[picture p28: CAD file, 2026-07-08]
STL(3d_printing)/Drill_Guide.stl
35.0 x 40.5 x 42.3

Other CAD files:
STL(3d_printing)/M5_Thick_Spacer2.stl
CAD/Custom/Platform.step
CAD/Custom/Spacers/M6_Spacer_11.81mm.step
STL(3d_printing)/Platform.stl
CAD/Custom/Spacers/M3_Thin_Spacer.step
CAD/Custom/Spacers/M6_Spacer_10.19mm.step
CAD/Custom/Spacers/M6_Spacer_23mm.step
STL(3d_printing)/Bearing_Housing.stl
STL(3d_printing)/Circuit_Organizer.stl
STL(3d_printing)/M5_Spacer_10mm.stl
STL(3d_printing)/M5_Spacer_10mm_Final.stl
STL(3d_printing)/M5_Spacer_11.5mm.stl
STL(3d_printing)/M6_Spacer_10.19mm.stl
STL(3d_printing)/M6_Spacer_11.81mm.stl
STL(3d_printing)/M6_Spacer_23mm.stl
STL(3d_printing)/Pendulum_Stick.stl
STL(3d_printing)/Tslot_Holder1.stl
STL(3d_printing)/Tslot_holder2.stl

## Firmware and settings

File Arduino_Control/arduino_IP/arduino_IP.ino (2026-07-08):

#include <Arduino.h>

// ***PINs***
const uint8_t PIN_ANGLE = A0; // P3022 output, A0
const uint8_t PIN_STEP = 2; // STEP, D2
const uint8_t PIN_DIR = 3; // Direction, D3
const uint8_t PIN_EN = 4; // Enable, D4

// ***Motor driver, LOW = motor ON***
const bool ENABLE_ACTIVE_LOW = true;

// ***Constants***
const unsigned long CONTROL_INTERVAL_US = 5000;

// STEP-pulse spacing limits
const unsigned long MIN_STEP_INTERVAL_US = 500;
const unsigned long MAX_STEP_INTERVAL_US = 6100;
const unsigned int STEP_PULSE_US = 3; // STEP signal width

// PD Output = FORCE (Newtons) -> accel -> integrate to velocity -> step rate 
const float CART_MASS_KG     = 0.226; // cart-accel effective mass = Delta/C
const float MAX_CART_FORCE_N = 60.0;  // motor force limit
const int   DIR_SIGN       = 1;   // cart direction

// Safety
const float SAFETY_ANGLE_DEG = 90; 
const float MAX_X_M = 0.22; // usable half-travel
const int SAFETY_TRIP_COUNT = 7; // short noise debounce

// Homing
const bool HOME_ON_STARTUP = true;
const int HOMING_DIR = +1;
const unsigned long HOMING_STEP_INTERVAL_US = 8000; // slow

// Arming
const float ARM_ANGLE_DEG = 5.0;         // initial disturbance window
const unsigned long ARM_STABLE_MS = 500; // stay there for this long

// Serial debug
const bool DEBUG_ENABLED = true;
const unsigned long DEBUG_INTERVAL_MS = 200; // print interval

// Sensor Calibration Values
const float DEGREES_PER_COUNT = 360.0/1024.0; // Arduino = 10 bit

int ANGLE_OFFSET_COUNTS = 538; // Upright ADC Value
const int SENSOR_SIGN = +1;
const float TARGET_ANGLE_DEG = 0.0;
const float TARGET_X_M = 0.0;

// Cart drive geometry
const int   FULL_STEPS_PER_REV = 200;   // 1.8 deg NEMA 17
const int   MICROSTEPS         = 1;    // DRV8825 microstep setting
const float PULLEY_CIRCUM_M    = 0.040; // GT2 20T pulley: 2 mm pitch * 20T
const float METERS_PER_STEP    = PULLEY_CIRCUM_M / (FULL_STEPS_PER_REV * MICROSTEPS);
const float V_MAX = METERS_PER_STEP / (MIN_STEP_INTERVAL_US * 1e-6f); 
const float V_MIN = METERS_PER_STEP / (MAX_STEP_INTERVAL_US * 1e-6f); 
const float DEG2RAD = PI / 180.0f;

// PD Gains
float kp_theta = 11.0, kd_theta = 1.7;
float kp_x = 2.0, kd_x = 1.2;

// float kp_theta = 12.0, kd_theta = 2.4;   // saved set
// float kp_x = 1.7, kd_x = 1.3;

const float TAU_D = 0.02; // derivative low-pass filter constant

// ***Variable Control Variables***
int rawAngle = 0; // prev raw ADC
float currentAngleDeg = 0.0;
float cartX_m = 0.0;

// PD variables
float thetaErr=0, thetaDeriv=0, thetaPrev=0;
float xErr=0, xDeriv=0, xPrev=0;
float force = 0.0;
float vCmd  = 0.0;
long stepCount = 0; // net steps from center
unsigned long lastControlUs = 0, lastStepUs = 0, lastDebugMs=0; // when things last happened
bool safetyTripped = false;

// ***Functions***

// angle & pos reading
float readAngle() {
  const int N_SAMPLES       = 6;   // oversample
  const int MAX_JUMP_COUNTS = 40;  // ~14 deg/tick (bigger jump = noise)
  static int rejectCount = 0;      // consecutive rejected readings

  long sum = 0;
  for (int i = 0; i < N_SAMPLES; i++) sum += analogRead(PIN_ANGLE); // oversample
  int avg = (int)(sum / N_SAMPLES); // average

  if (avg > 5 && avg < 1018 && abs(avg - rawAngle) < MAX_JUMP_COUNTS) {
    rawAngle = avg; rejectCount = 0;   // plausible -> accept
  } else if (++rejectCount >= 4) {
    rawAngle = avg; rejectCount = 0;   // persisted 4 ticks -> accept
  }                                    // else: hold last good rawAngle

  return SENSOR_SIGN * (rawAngle - ANGLE_OFFSET_COUNTS) * DEGREES_PER_COUNT;
}

float readCartPosition() {
  return stepCount * METERS_PER_STEP;
}

void computePD(float dt) {
  if (dt <= 0.0f) return; // if dt too small, don't compute PD

  // errors (rad, rad/s, m, m/s)
  float thErr = (currentAngleDeg - TARGET_ANGLE_DEG) * DEG2RAD;
  float rawDth = (thErr - thetaPrev) / dt;
  thetaDeriv += (rawDth - thetaDeriv) * (dt / (TAU_D + dt)); // filtered
  thetaPrev = thErr;

  float xE = cartX_m - TARGET_X_M;
  float rawDx = (xE - xPrev) / dt;
  xDeriv += (rawDx - xDeriv) * (dt / (TAU_D + dt)); // filtered
  xPrev = xE; 

  // PD Output (Newtons)
  force = kp_theta * thErr + kd_theta * thetaDeriv + kp_x * xE + kd_x * xDeriv;

  // clamp force to limit
  force = constrain(force, -MAX_CART_FORCE_N, MAX_CART_FORCE_N);

  // force -> cart acceleration -> integrate to velocity
  float aCmd = force / CART_MASS_KG;
  vCmd += aCmd * dt; 
  if (vCmd >  V_MAX) vCmd =  V_MAX; 
  if (vCmd < -V_MAX) vCmd = -V_MAX; 

  thetaErr = thErr; // radians
  xErr = xE; 
}
// Motor driver
void driveStepper() {
  float speed = fabs(vCmd);
  if (speed < V_MIN) return; // slower than min step rate -> hold 

  int dir = (DIR_SIGN * vCmd >= 0.0f) ? +1 : -1; 
  digitalWrite(PIN_DIR, (dir > 0) ? HIGH : LOW);

  unsigned long interval = (unsigned long)(METERS_PER_STEP / speed * 1e6f); // us per step
  if (interval < MIN_STEP_INTERVAL_US) interval = MIN_STEP_INTERVAL_US; 
  if (interval > MAX_STEP_INTERVAL_US) interval = MAX_STEP_INTERVAL_US; 

  unsigned long nowUs = micros();
  if (nowUs - lastStepUs >= interval) {
    lastStepUs = nowUs;
    digitalWrite(PIN_STEP, HIGH);
    delayMicroseconds(STEP_PULSE_US);
    digitalWrite(PIN_STEP, LOW);
    stepCount += dir; 
  }
}

// Safety check
void safetyCheck() {
  static int overAngleCount = 0;

  // Angle comes from the ADC, which can spike from motor noise -> debounce it.
  if (fabs(currentAngleDeg) > SAFETY_ANGLE_DEG) {
    if (++overAngleCount >= SAFETY_TRIP_COUNT) safetyTripped = true;
  } else {
    overAngleCount = 0; // any good reading clears the count (only consecutive spikes matter)
  }

  // Position comes from stepCount (a clean integer, never spikes) -> trip immediately.
  if (fabs(cartX_m) > MAX_X_M) safetyTripped = true;

  if (safetyTripped) {
    digitalWrite(PIN_STEP, LOW);
    enableDriver(false);
  }
}

void enableDriver(bool on) {
  bool pinHigh = ENABLE_ACTIVE_LOW ? (!on) : on;
  digitalWrite(PIN_EN, pinHigh ? HIGH : LOW);
}

// Homing slow step pulse
void homePulse() {
  digitalWrite(PIN_STEP, HIGH);
  delayMicroseconds(STEP_PULSE_US);
  digitalWrite(PIN_STEP, LOW);
  delayMicroseconds(HOMING_STEP_INTERVAL_US);
}

// Homing
void homeCart() {
  long fullTravel = (long)(2.0f * MAX_X_M / METERS_PER_STEP); // full travel in steps
  long seat = (long)(fullTravel * 1.2f); // slight overshoot length
  long half = fullTravel/2; // half travel in steps

  // drive towards end
  digitalWrite(PIN_DIR, (HOMING_DIR > 0) ? HIGH : LOW);
  for (long i = 0; i < seat; i++) homePulse();

  // back off to the center
  digitalWrite(PIN_DIR, (HOMING_DIR > 0) ? LOW : HIGH);
  for (long i = 0; i < half; i++) homePulse();

  stepCount = 0; // x = 0
}

// Arming gate after homing
void waitForUpright() {
  unsigned long inWindowSince = 0; // millis() when we entered the window (0 = not in)
  unsigned long lastMsgMs = 0;
  Serial.println(F("# Homing done. Raise the pendulum upright to arm..."));

  for (;;) {
    currentAngleDeg = readAngle();
    unsigned long nowMs = millis();

    if (fabs(currentAngleDeg - TARGET_ANGLE_DEG) <= ARM_ANGLE_DEG) {
      if (inWindowSince == 0) inWindowSince = nowMs;   
      if (nowMs - inWindowSince >= ARM_STABLE_MS) {    
        Serial.println(F("# Armed. Balancing..."));
        return;
      }
    } else {
      inWindowSince = 0;                               
    }

    if (nowMs - lastMsgMs >= 500) {                    
      lastMsgMs = nowMs;
      Serial.print(F("# waiting... angle=")); Serial.print(currentAngleDeg, 1);
      Serial.println(F(" deg"));
    }
  }
}

// Debug
void debugPrint() {
  Serial.print("raw=");      Serial.print(rawAngle);
  Serial.print("  th=");     Serial.print(currentAngleDeg, 2);
  Serial.print("deg  x=");   Serial.print(cartX_m * 100.0, 2);
  Serial.print("cm  e_th="); Serial.print(thetaErr * 180.0 / PI, 2); 
  Serial.print("deg  e_x="); Serial.print(xErr * 100.0, 2); 
  Serial.print("cm  F=");    Serial.print(force, 2); 
  Serial.print("N  v=");     Serial.print(vCmd, 3); 
  Serial.print("  steps=");  Serial.print(stepCount);
  if (safetyTripped) Serial.print("   [SAFETY TRIP - press RESET]");
  Serial.println();
}

// ***Main Functions***

void setup() {
  pinMode(PIN_STEP, OUTPUT);
  pinMode(PIN_DIR, OUTPUT);
  pinMode(PIN_EN, OUTPUT);
  digitalWrite(PIN_STEP, LOW);
  digitalWrite(PIN_DIR, LOW);
  enableDriver(true);

  Serial.begin(115200); // baud rate

  if (HOME_ON_STARTUP) homeCart();
  else stepCount = 0; // if homing = false, current position = center

  waitForUpright();

  thetaPrev = (currentAngleDeg - TARGET_ANGLE_DEG) * DEG2RAD;
  thetaDeriv = 0;
  xPrev = 0; xDeriv = 0;
  force = 0; vCmd = 0;

  unsigned long now = micros(); // current time [Us]
  lastControlUs = now; lastStepUs = now; lastDebugMs = millis();
}

void loop() {
  unsigned long nowUs = micros();

  if (nowUs - lastControlUs >= CONTROL_INTERVAL_US){
    float dt = (nowUs-lastControlUs)*1e-6f;
    lastControlUs = nowUs;

    currentAngleDeg = readAngle();
    cartX_m = readCartPosition();
    safetyCheck();

    // print one snapshot the instant the safety trips
    static bool tripPrinted = false;
    if (safetyTripped && !tripPrinted) { debugPrint(); tripPrinted = true; }

    if (!safetyTripped) computePD(dt); // PD
  }

  if (!safetyTripped) driveStepper();

  // periodic debug (one last line prints when trips)
  if (DEBUG_ENABLED && !safetyTripped && (millis() - lastDebugMs >= DEBUG_INTERVAL_MS)) {
    lastDebugMs = millis();
    debugPrint();
  }
}

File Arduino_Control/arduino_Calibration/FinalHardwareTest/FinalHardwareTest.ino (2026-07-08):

// Confirm the sensor AND motor work together before enabling closed-loop control.  
// Drives the motor while continuously displaying the live sensor reading and the current motor state.

// sensor (from arduino_IP.ino)
const uint8_t PIN_ANGLE = A0;
const float   VREF              = 5.0;
const float   ADC_FULLSCALE     = 1023.0;
const float   DEGREES_PER_COUNT = 360.0 / 1024.0;
const int     SENSOR_SIGN       = +1;
int           ANGLE_OFFSET_COUNTS = 538;

// motor (from arduino_IP.ino)
const uint8_t PIN_STEP = 2;
const uint8_t PIN_DIR  = 3;
const uint8_t PIN_EN   = 4;
const bool    ENABLE_ACTIVE_LOW = true;
const unsigned int  STEP_PULSE_US        = 3;
const unsigned long MIN_STEP_INTERVAL_US = 200;
const unsigned long MAX_STEP_INTERVAL_US = 6100;

// run state
unsigned long stepInterval = 2500;
unsigned long lastStepUs   = 0;
unsigned long lastFlipMs   = 0;
unsigned long lastPrintMs  = 0;
const unsigned long REVERSE_PERIOD_MS = 1000;
const unsigned long PRINT_PERIOD_MS   = 200;
bool running = false;
int  dir     = +1;

void enableDriver(bool on) {
  bool pinHigh = ENABLE_ACTIVE_LOW ? (!on) : on;
  digitalWrite(PIN_EN, pinHigh ? HIGH : LOW);
}

void printStatus() {
  int   raw   = analogRead(PIN_ANGLE);
  float volt  = raw * VREF / ADC_FULLSCALE;
  float angle = SENSOR_SIGN * (raw - ANGLE_OFFSET_COUNTS) * DEGREES_PER_COUNT;
  Serial.print(F("raw:"));    Serial.print(raw);
  Serial.print(F("\tvolt:"));  Serial.print(volt, 3);
  Serial.print(F("\tangle:")); Serial.print(angle, 2);
  Serial.print(F("\tdir:"));   Serial.print(running ? (dir > 0 ? F("FWD") : F("REV")) : F("STOP"));
  Serial.print(F("\tinterval:"));Serial.println(running ? stepInterval : 0UL);
}

void setup() {
  pinMode(PIN_STEP, OUTPUT);
  pinMode(PIN_DIR,  OUTPUT);
  pinMode(PIN_EN,   OUTPUT);
  digitalWrite(PIN_STEP, LOW);
  enableDriver(false);

  Serial.begin(115200);
  Serial.println(F("# Final Hardware Test (sensor + motor together)"));
  Serial.println(F("# g=go  s=stop  +=faster  -=slower"));
}

void loop() {
  // commands
  if (Serial.available()) {
    char c = Serial.read();
    if      (c == 'g') { running = true;  enableDriver(true);  lastFlipMs = millis(); }
    else if (c == 's') { running = false; enableDriver(false); }
    else if (c == '+') { if (stepInterval > MIN_STEP_INTERVAL_US) stepInterval -= 200; }
    else if (c == '-') { if (stepInterval < MAX_STEP_INTERVAL_US) stepInterval += 200; }
  }

  // auto-reverse so the cart doesn't run off the rail
  if (running && millis() - lastFlipMs >= REVERSE_PERIOD_MS) {
    lastFlipMs = millis();
    dir = -dir;
  }

  // non-blocking stepping
  if (running) {
    digitalWrite(PIN_DIR, (dir > 0) ? HIGH : LOW);
    unsigned long nowUs = micros();
    if (nowUs - lastStepUs >= stepInterval) {
      lastStepUs = nowUs;
      digitalWrite(PIN_STEP, HIGH);
      delayMicroseconds(STEP_PULSE_US);
      digitalWrite(PIN_STEP, LOW);
    }
  }

  // live readout (sensor + motor state)
  if (millis() - lastPrintMs >= PRINT_PERIOD_MS) {
    lastPrintMs = millis();
    printStatus();
  }
}

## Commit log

2026-07-08 Remove unused KiCad files and add gitignore
    [IP_Circuit_Schematics.kicad_pcb]
2026-07-08 Update README and circuit schematic
    [IP_Circuit_Schematics.kicad_sch]
